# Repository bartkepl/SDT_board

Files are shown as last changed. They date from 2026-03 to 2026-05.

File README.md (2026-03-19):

# SDT (SCPI Display Thermometer)
Benchtop thermometer with SCPI and USB.

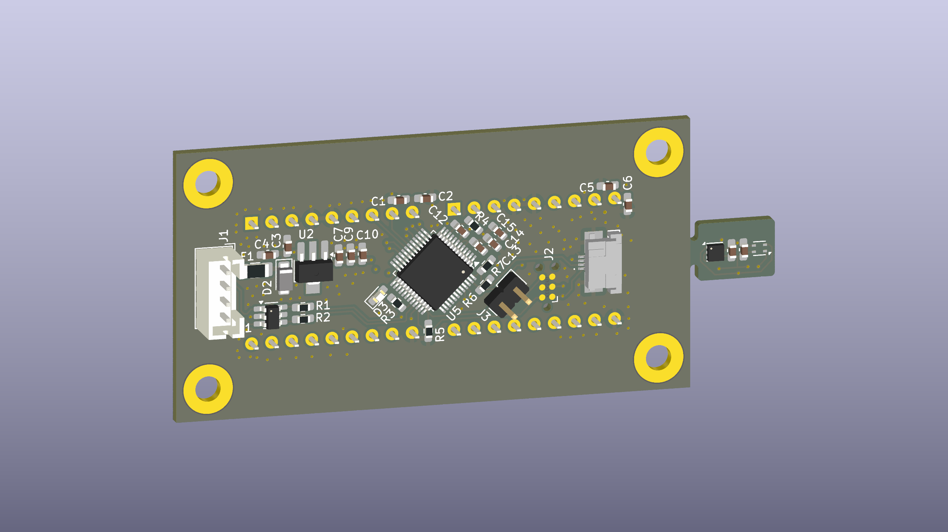
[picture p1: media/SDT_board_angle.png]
SCPI Display Thermometer


---
## Status : WIP

- [x] First revision of schematic and PCB is done.
- [x] PCB and parts ordered
- [ ] Prototypes assembled and tested
- [ ] Firmware

---
## Features:
- 4 layer board
- ARM Cortex-M0+ Processor in LQFP48 (STM32C071CBT6) 
- USB 2.0
- TMP117 or/and SHT45 for temperature measurement
----

## License and Contribution

Idea based on [SCPI Capable Thermometer](https://sebastianharnisch.de/scpi-enabled-thermometer/)

Display part & footprint from [kicad-intelligent-displays](https://github.com/74hc595/kicad-intelligent-displays) by [74hc595](https://github.com/74hc595)

USB-TMC library from TinyUSB [TinyUSB](https://github.com/hathach/tinyusb)

SCPI parser library from [scpi-parser](https://github.com/j123b567/scpi-parser) by [Jan Breuer](https://github.com/j123b567)

[MIT License](/LICENSE)

Open to contributions in both software and hardware!

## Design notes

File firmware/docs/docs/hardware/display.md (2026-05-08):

# Wyświetlacz DLR2416

SDT Board używa dwóch modułów **DLR2416** tworząc łącznie **8-znakowy wyświetlacz LED dot-matrix**.

---

## Co to jest DLR2416?

**DLR2416** to inteligentny 4-znakowy wyświetlacz LED z wbudowanym generatorem znaków. Każdy moduł zawiera:

- 4 pozycje znakowe (A–D)
- Wyświetlanie ASCII (5×7 pikseli na znak)
- Wewnętrzną pamięć RAM na 4 znaki
- Interfejs równoległy 7-bitowy (D0–D6)
- Wbudowany dekoder adresu pozycji (A0–A1 → 4 pozycje)

Dwa moduły (DISP1 i DISP2) są połączone równolegle na jednej szynie danych, wybierane oddzielnie sygnałami CE (Chip Enable).

---

## Schemat połączenia

```
STM32C071               DISP1 (pozycje 0–3)    DISP2 (pozycje 4–7)
                         ┌──────────────┐        ┌──────────────┐
PA0–PA6  ──── D0–D6  ───►│              │        │              │
PA7      ──── A0     ───►│   DLR2416    │        │   DLR2416    │
PB0      ──── A1     ───►│              │        │              │
PB1 (INV)─── WR     ───►│              │        │              │
PB2 (INV)─── CLR    ───►│              │        │              │
PB3 (INV)─── CE1    ───►│              │        │              │
PB4 (INV)─── CE2    ───►│              │        │              │
PB12(INV)─── CU     ───►│              │        │              │
PB13     ──── CUE   ───►│              │        │              │
             └──────────────┘        └──────────────┘
                                            ▲              ▲
PB5 (INV)─── CE1 ─────────────────────────┘              │
PB6 (INV)─── CE2 ──────────────────────────────────────────┘

PC14     ──── BL (PWM) ──────────── podświetlenie LED (wspólne)
```

---

## Sygnały sterujące

| Pin | Sygnał | Aktywny | Opis |
|-----|---|---|---|
| PA0–PA6 | D0–D6 | — | 7-bitowa szyna danych (kod ASCII) |
| PA7 | A0 | — | Adres pozycji bit 0 |
| PB0 | A1 | — | Adres pozycji bit 1 |
| PB1 | WR | LOW | Strob zapisu (zapis przy opadającym zboczu) |
| PB2 | CLR | LOW | Wyczyszczenie pamięci wyświetlacza |
| PB3 | CE1_1 | LOW | Chip Enable 1 — DISP1 |
| PB4 | CE2_1 | LOW | Chip Enable 2 — DISP1 |
| PB5 | CE1_2 | LOW | Chip Enable 1 — DISP2 |
| PB6 | CE2_2 | LOW | Chip Enable 2 — DISP2 |
| PB12 | CU | LOW | Chip Unit: HIGH=dane, LOW=komenda |
| PB13 | CUE | — | Chip Unit Enable — zatrzask komendy |
| PC14 | BL | PWM | Podświetlenie — TIM3 CH2, AF11 |

---

## Adresowanie pozycji

| A1 | A0 | Pozycja (4 znaki na moduł) |
|----|----|---|
| 0 | 0 | Pozycja 0 (skrajna lewa) |
| 0 | 1 | Pozycja 1 |
| 1 | 0 | Pozycja 2 |
| 1 | 1 | Pozycja 3 (skrajna prawa modułu) |

Dla 8-znakowego wyświetlacza:
- DISP1 obsługuje pozycje 0–3 (lewe 4 znaki)
- DISP2 obsługuje pozycje 4–7 (prawe 4 znaki)

---

## Protokół zapisu znaku

Procedura zapisu jednego znaku:

1. Ustaw adres: A1, A0 = numer pozycji (0–3)
2. Ustaw dane: D0–D6 = kod ASCII znaku
3. Wybierz moduł: CE1=LOW, CE2=LOW (odpowiedni moduł)
4. Strob zapisu: WR=LOW, następnie WR=HIGH

---

## Konfiguracja orientacji: SWAP i REVERSE

W `dlr2416.c` dwie stałe kompilacji wpływają na `DLR2416_WriteString8()`:

```c
#define SWAP_DISPLAYS 1   // zamień DISP1↔DISP2 (domyślnie: 1)
#define REVERSE_CHARS 1   // odwróć kolejność znaków w module pos=3-i (domyślnie: 1)
```

| Stała | Efekt |
|---|---|
| `SWAP_DISPLAYS 1` | Znaki 0–3 idą do DISP2, znaki 4–7 do DISP1 |
| `REVERSE_CHARS 1` | Pozycja i → 3-i (odwrócona kolejność wewnątrz modułu) |

Kombinacja obu pozwala dopasować wyświetlanie do fizycznej orientacji modułów na płytce bez zmiany okablowania.

---

## Sterowanie jasnością (PWM)

Jasność sterowana jest sygnałem **PWM** przez **TIM3 Channel 2** na pinie **PC14** (AF11).

| Parametr | Wartość |
|---|---|
| TIM3 ARR (Period) | **255** (8-bit, skonfigurowane w CubeMX) |
| Formuła CCR | `(1199 × percent) / 100` |
| CCR przy 1% | 11 |
| CCR przy 21% | 251 (~= ARR) |
| CCR przy ≥22% | > 255 → pin zawsze HIGH (100% brightness) |
| Domyślny CCR (init) | 600 → zawsze HIGH (pełna jasność po starcie) |
| Wyłączony | `DLR2416_PWM_Disable(GPIO_PIN_RESET)` — pin jako GPIO LOW |

```c
/* Kod w DLR2416_SetBrightness() */
uint16_t value = (1199 * percent) / 100;
__HAL_TIM_SET_COMPARE(&htim3, TIM_CHANNEL_2, value);
```

!!! warning "Efektywna regulacja tylko ≤21%"
    TIM3 ARR = 255. Dla brightness ≥ 22%, CCR przekracza ARR i pin pozostaje
    ciągle HIGH (100% jasność). Regulacja PWM działa tylko dla wartości 1–21%.
    Powyżej efekt jest identyczny — maksymalna jasność.

---

## Znak stopnia

Wyświetlacz nie obsługuje standardowego znaku stopnia (°, ASCII 0xB0). Zamiast tego DLR2416 używa własnego kodu:

```c
#define DEGREE_CHAR 0x1B   /* Specjalny znak stopnia DLR2416 */
```

Firmware używa go automatycznie podczas formatowania temperatury w trybie pomiarowym.

---

## Format wyświetlania temperatury

W trybie `SOURce 0` (pomiarowy) firmware formatuje temperaturę przez `ConvertFloatTempToChar()`.

Format: dokładnie **8 bajtów**. Ostatni bajt to `DEGREE_CHAR` = `0x1B`. **Brak litery 'C'**.

```
Mapa pozycji: [0]  [1][2][3][4][5]  [6]  [7]
               sign  cyfry/kropka    spc   °

Przykłady (hex + ASCII):
 25.47°  →  20 32 35 2E 34 37 20 1B  = " 25.47 °"
-10.11°  →  2D 31 30 2E 31 31 20 1B  = "-10.11 °"
 3.500°  →  20 33 2E 35 30 30 20 1B  = " 3.500 °"
```

Zakres:
- `|T| < 10` → format `±D.DDD` (3 miejsca po przecinku)
- `|T| ≥ 10` → format `±DD.DD` (2 miejsca po przecinku)

---

## Komunikaty błędów

Gdy wystąpi błąd czujnika, wyświetlacz pokazuje:

```
ERR:-241
ERR:-240
ERR:-230
```

- Format: `ERR:XXXX` (8 znaków)
- Czas wyświetlania: **1500 ms** na błąd
- Kolejka: max **4 błędy**
- Po wyczyszczeniu: powrót do poprzedniego widoku

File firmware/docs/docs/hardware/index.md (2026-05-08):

# Sprzęt — Przegląd

SDT Board zbudowany jest na mikrokontrolerze **STM32C071CBT6** (ARM Cortex-M0+) z trzema głównymi interfejsami sprzętowymi: I2C do czujników, USB do komunikacji z komputerem i GPIO do sterowania wyświetlaczem.

---

## Mikrokontroler

| Parametr | Wartość |
|---|---|
| Model | STM32C071CBT6 |
| Rdzeń | ARM Cortex-M0+ |
| Częstotliwość | 48 MHz (HSI48 + CRS — synchronizacja z USB) |
| Flash | 128 KB |
| RAM | 12 KB |
| Obudowa | LQFP48 |
| Narzędzie konfiguracji | STM32CubeMX (plik `SDT_board.ioc`) |

---

## Interfejsy i peryferia

| Peryferium | Zastosowanie | Uwagi |
|---|---|---|
| **I2C1** | Komunikacja z czujnikami | DMA-enabled (TX: DMA1_CH1, RX: DMA1_CH2) |
| **USB** | USB 2.0 Device (USB-TMC) | Zasilany z USB, synchronizacja zegara przez CRS |
| **TIM3 CH2** | PWM sterowanie jasnością wyświetlacza | AF11, PC14, ARR=255, formuła CCR=1199×%/100 |
| **CRC** | Walidacja danych z SHT45 | Sprzętowy kalkulator CRC |
| **DMA1_CH1/CH2** | Transmisja I2C | Odciąża CPU podczas pomiaru |

---

## Mapa pinów GPIO

### Port A — szyna danych wyświetlacza

| Pin | Sygnał | Kierunek | Opis |
|-----|---|---|---|
| PA0 | D0 | Out | Bit 0 szyny danych wyświetlacza |
| PA1 | D1 | Out | Bit 1 szyny danych wyświetlacza |
| PA2 | D2 | Out | Bit 2 szyny danych wyświetlacza |
| PA3 | D3 | Out | Bit 3 szyny danych wyświetlacza |
| PA4 | D4 | Out | Bit 4 szyny danych wyświetlacza |
| PA5 | D5 | Out | Bit 5 szyny danych wyświetlacza |
| PA6 | D6 | Out | Bit 6 szyny danych wyświetlacza |
| PA7 | A0 | Out | Linia adresowa 0 (wybór pozycji) |
| PA10 | LED | Out | Dioda LED statusu |

### Port B — sterowanie wyświetlaczem

| Pin | Sygnał | Kierunek | Logika | Opis |
|-----|---|---|---|---|
| PB0 | A1 | Out | — | Linia adresowa 1 (wybór pozycji) |
| PB1 | WR | Out | Aktywny LOW | Zapis — strob zapisu |
| PB2 | CLR | Out | Aktywny LOW | Czyszczenie pamięci wyświetlacza |
| PB3 | CE1_1 | Out | Aktywny LOW | Chip Enable 1 wyświetlacza 1 |
| PB4 | CE2_1 | Out | Aktywny LOW | Chip Enable 2 wyświetlacza 1 |
| PB5 | CE1_2 | Out | Aktywny LOW | Chip Enable 1 wyświetlacza 2 |
| PB6 | CE2_2 | Out | Aktywny LOW | Chip Enable 2 wyświetlacza 2 |
| PB12 | CU | Out | Aktywny LOW | Chip Unit — tryb DANE/KOMENDA |
| PB13 | CUE | Out | — | Chip Unit Enable — zatrzask komendy |

### Port C

| Pin | Sygnał | Kierunek | Opis |
|-----|---|---|---|
| PC14 | BL | PWM Out | Podświetlenie LED — TIM3 CH2, AF11 |

---

## Topologia I2C

```
STM32C071
    │
    ├── I2C1 (DMA) ─── SDA/SCL
    │                      │
    │              ┌────────┴────────┐
    │           TMP117            SHT45
    │          addr 0x48         addr 0x44
    │          (temp)            (T + RH)
```

Oba czujniki dzielą jeden magistralę I2C. W trybie DUAL używany jest globalny mutex (`g_i2c_active_sensor`) zapobiegający konfliktu na szynie.

---

## Schemat zasilania

| Napięcie | Źródło |
|---|---|
| VBUS 5V | USB |
| VDD 3,3V | Regulator na płytce |

---

## Linki

- [Czujniki](sensors.md) — TMP117 i SHT45 — specyfikacje i tryby pracy
- [Wyświetlacz DLR2416](display.md) — protokół i pinout

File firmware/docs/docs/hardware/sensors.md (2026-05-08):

# Czujniki

SDT Board obsługuje dwa czujniki temperatury: **TMP117** (temperatura) i **SHT45** (temperatura + wilgotność). Oba używają tego samego magistrali I2C. Wykrywane są automatycznie podczas uruchamiania — można też używać obydwu jednocześnie (tryb DUAL).

---

## TMP117 — Czujnik temperatury

### Parametry elektryczne

| Parametr | Wartość |
|---|---|
| Adres I2C | `0x48` (8-bit: `0x90`) |
| Napięcie zasilania | 1,7–5,5 V |
| Pobór prądu | 3,5 µA @ 1 pom./s |
| Zakres temperatury | -55 °C … +150 °C |
| Dokładność typowa | ±0,1 °C (0–70 °C) |
| Rozdzielczość | **7,8125 m°C/LSB** (0,0078125 °C) |
| Interfejs | I2C (standardowy / fast mode) |

### Konwersja temperatury

Temperatura przechowywana jest w rejestrze `0x00` jako 16-bitowa liczba ze znakiem (uzupełnienie do dwóch):

```
T [°C] = raw_int16 × 0.0078125
```

**Przykład:** `raw = 0x0C80` = 3200 → T = 3200 × 0.0078125 = **25,00 °C**

### Rejestry

| Adres | Nazwa | Dostęp | Opis |
|---|---|---|---|
| `0x00` | TEMP | R | Wynik pomiaru temperatury |
| `0x01` | CONFIG | R/W | Konfiguracja: tryb, CONV, AVG, alerty |
| `0x02` | THIGH | R/W | Górny próg alertu |
| `0x03` | TLOW | R/W | Dolny próg alertu |
| `0x0F` | ID | R | Identyfikator układu |

### Rejestr CONFIG (0x01) — Mapa bitów

| Bity | Nazwa | Opis |
|---|---|---|
| [15] | HIGH_ALERT | R — flaga: temperatura ≥ THIGH |
| [14] | LOW_ALERT | R — flaga: temperatura ≤ TLOW |
| [13] | DATA_READY | R — nowy pomiar gotowy |
| [12] | EEPROM_BUSY | R — EEPROM zajęty |
| [11:10] | MOD[1:0] | R/W — tryb konwersji |
| [9:7] | CONV[2:0] | R/W — cykl konwersji |
| [6:5] | AVG[1:0] | R/W — sprzętowe uśrednianie |
| [1] | SOFT_RESET | W — reset programowy (auto-zeruje się) |

**Domyślna wartość CONFIG:** `0x0220` (MOD=Continuous, CONV=1s, AVG=8x)

### Tryby konwersji (MOD)

| Wartość | SCPI | Opis |
|---|---|---|
| `0x00` | `CONTinuous` | Ciągły pomiar |
| `0x01` | `SHUTdown` | Wyłączony — minimalne zużycie energii |
| `0x03` | `ONESHot` | Jeden pomiar, potem shutdown |

### Cykl konwersji (CONV) a tryb uśredniania (AVG)

Łączny czas pomiaru = czas konwersji × liczba próbek AVG:

| CONV kod | Czas (AVG=1) | Czas (AVG=8) | Czas (AVG=32) | Czas (AVG=64) |
|---|---|---|---|---|
| 0 | 15,5 ms | 125 ms | 500 ms | 1 s |
| 1 | 125 ms | 125 ms | 500 ms | 1 s |
| 2 | 250 ms | 250 ms | 500 ms | 1 s |
| 3 | 500 ms | 500 ms | 500 ms | 1 s |
| 4 | 1 s | 1 s | 1 s | 1 s |
| 5 | 4 s | 4 s | 4 s | 4 s |
| 6 | 8 s | 8 s | 8 s | 8 s |
| 7 | 16 s | 16 s | 16 s | 16 s |

### Alerty temperatury

TMP117 posiada sprzętowe alerty temperatury — wywoływane, gdy temperatura przekroczy progi THIGH lub TLOW. Progi przechowywane są w rejestrach i używają tego samego formatu co TEMP.

```python
inst.write('SENSor:ALERt:HIGH 80.0')    # alert przy T > 80 °C
inst.write('SENSor:ALERt:LOW -10.0')    # alert przy T < -10 °C
status = inst.query('SENSor:ALERt:STATus?')
```

---

## SHT45 — Czujnik temperatury i wilgotności

### Parametry elektryczne

| Parametr | Wartość |
|---|---|
| Adres I2C | `0x44` (8-bit: `0x88`) |
| Napięcie zasilania | 1,08–3,6 V |
| Pobór prądu | ~1 µA (standby) |
| Zakres temperatury | -40 °C … +125 °C |
| Zakres wilgotności | 0 % … 100 % RH |
| Dokładność T (typowa) | ±0,1 °C |
| Dokładność RH (typowa) | ±1,0 % RH |
| Interfejs | I2C |

### Konwersja pomiarów

```
T [°C] = -45 + 175 × (raw_T / 65535)
H [%RH] = -6 + 125 × (raw_H / 65535)
```

Każdy pomiar zawiera **CRC-8** dla walidacji integralności danych (generowany i sprawdzany przez firmware).

### Komendy SHT45

| Komenda (hex) | Stała | Opis | Czas pomiaru |
|---|---|---|---|
| `0xFD` | `SHT45_PRECISION_HIGH` | Pomiar — wysoka precyzja | ~125 ms |
| `0xF6` | `SHT45_PRECISION_MEDIUM` | Pomiar — średnia precyzja | ~50 ms |
| `0xE0` | `SHT45_PRECISION_LOW` | Pomiar — niska precyzja | ~13 ms |
| `0x89` | — | Odczyt numeru seryjnego | — |
| `0x94` | — | Soft reset | — |

### Grzałka (heater)

SHT45 posiada wbudowaną grzałkę do usuwania kondensacji lub testowania odpowiedzi czujnika:

| Stała | Hex | Moc | Czas | Opis |
|---|-----|-----|---|---|
| `SHT45_HEATER_200MW_1S` | `0x39` | 200 mW | 1 s | Maksymalna moc, długi czas |
| `SHT45_HEATER_200MW_100MS` | `0x32` | 200 mW | 100 ms | Maksymalna moc, krótki czas |
| `SHT45_HEATER_110MW_1S` | `0x2F` | 110 mW | 1 s | Średnia moc, długi czas |
| `SHT45_HEATER_110MW_100MS` | `0x24` | 110 mW | 100 ms | Średnia moc, krótki czas |
| `SHT45_HEATER_20MW_1S` | `0x1E` | 20 mW | 1 s | **Domyślna** (SCPI) |
| `SHT45_HEATER_20MW_100MS` | `0x15` | 20 mW | 100 ms | Minimalna moc, krótki czas |

!!! warning "Po użyciu grzałki"
    Wyniki pomiarów po zakończeniu grzania są zawyżone. Odczekaj kilka sekund zanim użyjesz danych pomiarowych.

---

## Tryb DUAL — obydwa czujniki

Gdy oba czujniki są wykryte podczas inicjalizacji:

- **Dane temperatury** — pobierane z SHT45 (priorytet — ma też wilgotność)
- **Dane wilgotności** — pobierane z SHT45
- **TMP117** — działa równolegle (alerty, konfiguracja dostępna przez SCPI)
- **Arbitraż magistrali I2C** — globalny mutex `g_i2c_active_sensor` zapobiega konfliktom

---

## Auto-detekcja czujników

Podczas inicjalizacji firmware próbuje nawiązać komunikację z obydwoma adresami I2C:

1. Próba połączenia z TMP117 (`0x48`)
2. Próba połączenia z SHT45 (`0x44`)
3. Timeout detekcji: **5 sekund**
4. Jeśli żaden czujnik nie odpowie → SCPI błąd `-241` (Hardware missing)

```
*TST?  →  0   (czujnik wykryty i sprawny)
*TST?  →  1   (brak czujnika)
```

---

## Porównanie czujników

| Cecha | TMP117 | SHT45 |
|---|---|---|
| Temperatura | ✓ -55…+150 °C | ✓ -40…+125 °C |
| Wilgotność | ✗ | ✓ 0–100 %RH |
| Rozdzielczość T | 0,0078125 °C | zależy od precyzji |
| Sprzętowe uśrednianie | 1/8/32/64x | ✗ (softwarowe) |
| Softwarowe uśrednianie | ✗ | 1–255x |
| Alerty T | ✓ THIGH/TLOW | ✗ |
| Grzałka | ✗ | ✓ |
| Tryby konwersji | 3 tryby | precyzja LOW/MED/HIGH |
| CRC walidacja | ✗ | ✓ (CRC-8) |

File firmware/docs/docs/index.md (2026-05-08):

# SDT Board — Dokumentacja

**SDT** (SCPI Display Thermometer) to USB-termometr laboratoryjny z interfejsem SCPI, zbudowany na mikrokontrolerze STM32C071CBT6. Urządzenie mierzy temperaturę (i opcjonalnie wilgotność), wyświetla wyniki na 8-znakowym wyświetlaczu LED i udostępnia pełny interfejs sterowania przez USB.

---

## Przegląd systemu

```
┌─────────────────────────────────────────────────────────┐
│                     SDT Board                           │
│                                                         │
│  ┌──────────┐   I2C    ┌──────────┐  ┌──────────────┐  │
│  │  TMP117  │◄────────►│          │  │  DLR2416     │  │
│  │  (temp)  │          │STM32C071 │  │  8-znak LED  │  │
│  └──────────┘   I2C    │  CBT6    │─►│  wyświetlacz │  │
│  ┌──────────┐◄────────►│          │  └──────────────┘  │
│  │  SHT45   │          │          │                     │
│  │ (T + RH) │          │  USB-TMC │                     │
│  └──────────┘          └────┬─────┘                     │
│                             │                           │
└─────────────────────────────┼───────────────────────────┘
                              │ USB 2.0
                       ┌──────▼──────┐
                       │     PC      │
                       │  PyVISA /   │
                       │  LabVIEW /  │
                       │  Terminal   │
                       └─────────────┘
```

---

## Parametry urządzenia

| Cecha | Wartość |
|---|---|
| MCU | STM32C071CBT6 (ARM Cortex-M0+, 48 MHz) |
| Flash | 128 KB |
| RAM | 12 KB |
| Komunikacja | USB 2.0 Device — klasa USB-TMC |
| Protokół | SCPI (IEEE 488.2) |
| Identyfikacja | `bartkepl,SDT,<serial>,1.0` |
| Czujniki | TMP117 i/lub SHT45 (auto-detekcja) |
| Wyświetlacz | 8-znakowy LED dot-matrix (DLR2416 × 2) |
| Jasność | Regulowana PWM 1–100% |

---

## Obsługiwane czujniki

| Czujnik | Temperatura | Wilgotność | Adres I2C | Uwagi |
|---|---|---|---|---|
| TMP117 | -55 °C … +150 °C, ±0,1 °C | — | 0x48 | Wysokoprecyzyjny, alerty T |
| SHT45 | -40 °C … +125 °C | 0–100 % RH | 0x44 | Temp + wilgotność, grzałka |

Urządzenie wykrywa czujniki automatycznie podczas uruchamiania. Gdy oba są podłączone, działa w trybie **DUAL** — dane temperatury i wilgotności są zbierane z SHT45, a TMP117 może być używany równolegle.

---

## Szybki start

```bash
pip install pyvisa pyvisa-py
```

```python
import pyvisa
rm = pyvisa.ResourceManager('@py')
# VID=0xCAFE, PID=0x4000, numer seryjny USB: "SDT_<8charHash>"
inst = rm.open_resource('USB0::0xCAFE::0x4000::SDT_YOURHASH::INSTR')
print(inst.query('*IDN?'))
print(inst.query('SENSor:TEMPerature?'))
```

Więcej przykładów: [Pierwsze kroki](getting-started.md)

---

## Komendy SCPI

Urządzenie obsługuje ponad 30 komend SCPI:

- **[IEEE 488.2](scpi/ieee488.md)** — `*IDN?`, `*RST`, `*TST?` i inne standardowe
- **[SYSTem](scpi/system.md)** — błędy, wersja, ID MCU, reset, bootloader DFU
- **[SENSor](scpi/sensor.md)** — temperatura, wilgotność, tryby pracy, alerty
- **[DISPlay](scpi/display.md)** — jasność, stan, tekst, źródło danych

---

## Zasoby zewnętrzne

- Biblioteka SCPI: [scpi-parser (j123b567)](https://github.com/j123b567/scpi-parser)
- Stos USB: [TinyUSB](https://github.com/hathach/tinyusb)
- Inspiracja projektem: [Sebastian Harnisch — SCPI Thermometer](https://sebastianharnisch.de/scpi-enabled-thermometer/)

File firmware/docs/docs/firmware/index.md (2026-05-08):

# Architektura Firmware

Firmware SDT Board napisany jest w języku C (STM32 HAL + bare-metal) i oparty na współbieżnym modelu zadań (cooperative multitasking) — bez RTOS-a.

---

## Diagram przepływu danych

```
USB Host (PC)
      │
      │  USB 2.0 / USB-TMC
      ▼
┌─────────────────┐
│   TinyUSB       │  usbtmc_app.c
│   (USB stack)   │  — odbiera bajty USB
└────────┬────────┘  — buforuje komendy SCPI
         │ dane tekstowe (SCPI)
         ▼
┌─────────────────┐
│  SCPI Parser    │  libscpi / scpi-def.c
│  (libscpi)      │  — parsuje komendy
└───┬─────────────┘  — wywołuje handlery
    │           │
    ▼           ▼
┌───────┐  ┌───────────┐
│Sensor │  │  Display  │  — ustaw jasność
│ API   │  │  API      │  — ustaw tekst
│       │  │           │  — zmień źródło
└───┬───┘  └─────┬─────┘
    │             │
    ▼             ▼
┌─────────────────────────────────┐
│         I2C + GPIO              │
│  TMP117  │  SHT45  │  DLR2416  │
└─────────────────────────────────┘
```

---

## Pętla główna (main loop)

`Core/Src/main.c` — uruchamia po inicjalizacji peryferiów nieskończoną pętlę zadań:

```c
while (1) {
    tud_task();                /* TinyUSB — obsługa USB */
    usbtmc_app_task_iter();    /* USB-TMC — SCPI request/response */
    Sensor_Task();             /* Czujnik — maszyna stanów I2C */
    SCPI_Main_Poll();          /* SCPI — propagacja błędów czujnika */
    Display_task();            /* Wyświetlacz — odświeżanie LED */
}
```

Wszystkie zadania są **nieblokujące** (non-blocking) — każde sprawdza swój stan, wykonuje krok i oddaje sterowanie. Synchronizacja oparta na 1 ms timerze systemowym (`SysTick`).

---

## Inicjalizacja

Kolejność inicjalizacji przy starcie (`main.c`):

```
── HAL (generowane przez CubeMX) ──────────────────────────────────
 1. HAL_Init()            — inicjalizacja HAL STM32
 2. SystemClock_Config()  — HSI48 48 MHz + CRS synchronizacja z USB
 3. MX_GPIO_Init()        — GPIO (D0-D6, A0-A1, CE, WR, CLR, LED)
 4. MX_DMA_Init()         — DMA1 CH1/CH2 (I2C TX/RX)
 5. MX_I2C1_Init()        — I2C1 (timing 0x00402D41)
 6. MX_TIM3_Init()        — TIM3 PWM CH2 (podświetlenie, ARR=255)
 7. MX_USB_PCD_Init()     — USB DRD FS
 8. MX_CRC_Init()         — sprzętowy CRC

── Kod użytkownika ─────────────────────────────────────────────────
 9. Sensor_Init(&hi2c1)   — detekcja TMP117/SHT45, konfiguracja I2C
10. tud_init()            — TinyUSB stack
11. SCPI_Main_Init()      — parser SCPI + rejestracja komend + IDN
12. Display_Init()        — DLR2416_Init() + domyślna jasność 4%
```

---

## Moduły firmware

### `Core/Src/main.c`
Punkt wejścia. Inicjalizacja peryferiów i pętla główna.

### `Core/Src/usbtmc_app.c`
Obsługa protokołu USB-TMC:
- Odbieranie pakietów BULK OUT (komendy SCPI)
- Wysyłanie pakietów BULK IN (odpowiedzi SCPI)
- Zarządzanie stanem request/response (maszyna stanów)
- Wywołanie `SCPI_Main_Input()` gdy komenda jest kompletna

### `App/libscpi/src/scpi-def.c`
Rejestracja i implementacja wszystkich komend SCPI:
- Lista komend (`scpi_commands[]`) — mapowanie wzorców na handlery
- Implementacja 30+ handlerów C
- Propagacja błędów do kolejki SCPI
- Integracja z modułami sensor i display

### `App/sensor/sensor.c`
Zunifikowany interfejs czujnika:
- Auto-detekcja TMP117 i SHT45 na I2C podczas `Sensor_Init()`
- `Sensor_Task()` — wywołuje `TMP117_Task()` lub `SHT45_Task()` w zależności od wykrytego czujnika
- `g_sensor` — globalny obiekt z danymi (typ, temperatura, wilgotność, flagi)
- Propagacja błędów przez `Sensor_GetAndClearError()`
- Arbitraż magistrali I2C przez `g_i2c_active_sensor`

### `App/sensor/tmp117.c`
Sterownik TMP117:
- Maszyna stanów (26 stanów) obsługująca wszystkie transakcje I2C
- Asynchroniczny odczyt przez DMA — `TMP117_I2C_TxComplete_Callback()` / `TMP117_I2C_RxComplete_Callback()`
- Odczyt: temperatura, ID, CONFIG, THIGH, TLOW
- Zapis: CONFIG (tryb/AVG/CONV), THIGH, TLOW
- Obsługa timeout DMA (100 ms)

### `App/sensor/sht45.c`
Sterownik SHT45:
- Maszyna stanów (22 stany) obsługująca pomiar, serial, reset i grzałkę
- Asynchroniczny odczyt przez DMA
- Walidacja CRC-8 dla każdego pomiaru
- Softwarowe uśrednianie (akumulator próbek)
- Timeout DMA (100 ms)

### `App/D2416/display.c`
Zarządzanie wyświetlaczem:
- `Display_task()` — wywoływany co 100 ms, odświeża wyświetlacz
- Wybór źródła: pomiar (auto-format) lub tekst użytkownika
- Kolejka błędów (4 wpisy FIFO), każdy wyświetlany 1500 ms
- Sterowanie jasnością przez `DLR2416_SetBrightness()`

### `App/D2416/dlr2416.c`
Niskopoziomowy sterownik DLR2416:
- Bit-banged GPIO dla szyny danych i sygnałów sterujących
- `DLR2416_WriteChar()` — zapis jednego znaku na pozycję
- `DLR2416_WriteString8()` — zapis 8 znaków na cały wyświetlacz
- `DLR2416_SetBrightness()` — sterowanie PWM TIM3
- `DLR2416_PWM_Enable()` / `DLR2416_PWM_Disable()` — włącz/wyłącz

### `App/Utils/Utils.c`
Funkcje pomocnicze:
- `SysTimZeroTimer1ms_u16()` — start timera 1 ms
- `SysTimTestTimer1ms_u16()` — sprawdzenie czy minął czas (wrap-safe, 16-bit)
- `serial_get()` — **8-znakowy** FNV-1a hash z 20 B danych MCU (DEVID+REVID+UID)
- `serial_get_full()` — **40-znakowy** hex dump tych 20 bajtów

---

## Obsługa błędów

```
Sensor_Task()
    │
    ├── Błąd I2C → ustaw SENSOR_ERR_COMM
    ├── Timeout DMA → ustaw SENSOR_ERR_TIMEOUT
    └── Błąd CRC → ustaw SENSOR_ERR_DATA

SCPI_Main_Poll()  (wywoływany co iterację)
    │
    └── Sensor_GetAndClearError()
           │
           ├── SENSOR_ERR_NOT_FOUND → SCPI_ErrorPush(-241)
           ├── SENSOR_ERR_COMM → SCPI_ErrorPush(-240)
           ├── SENSOR_ERR_TIMEOUT → SCPI_ErrorPush(-365)
           └── SENSOR_ERR_DATA → SCPI_ErrorPush(-230)

SCPI_Error callback
    │
    └── Display_ShowError(code)  → wyświetl "ERR:XXXX" przez 1.5s
```

---

## Okresy zadań

| Zadanie | Okres wywołania | Uwagi |
|---|---|---|
| `tud_task()` | Co iterację pętli | USB — as fast as possible |
| `usbtmc_app_task_iter()` | Co iterację pętli | USB-TMC state machine |
| `Sensor_Task()` | Co iterację pętli | Wewnętrzny timer 10 ms |
| `SCPI_Main_Poll()` | Co iterację pętli | Sprawdza błędy czujnika |
| `Display_task()` | Co iterację pętli | Wewnętrzny timer 100 ms |
| Odczyt czujnika | 1000 ms domyślnie | Konfigurowalny przez SCPI |

---

## Linki do API

- [API czujników](sensor-api.md) — funkcje C dla TMP117, SHT45 i warstwy sensor
- [API wyświetlacza](display-api.md) — funkcje C dla display i DLR2416

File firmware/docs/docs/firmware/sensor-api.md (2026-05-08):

# API czujników (C)

Dokumentacja publicznych funkcji i typów danych modułów sensor, tmp117 i sht45.

---

## Typy danych

### `SensorType_t` (`sensor.h`)

Enum identyfikujący aktywny czujnik.

```c
typedef enum {
    SENSOR_NONE  = 0,   // Żaden czujnik nie wykryty
    SENSOR_TMP117,      // Tylko TMP117
    SENSOR_SHT45,       // Tylko SHT45
    SENSOR_DUAL,        // Oba czujniki
    SENSOR_ERROR,       // Błąd komunikacji z czujnikiem
} SensorType_t;
```

### `SensorError_t` (`sensor.h`)

Enum błędów generowanych przez moduł sensor. Propagowane przez `SCPI_Main_Poll()` do kolejki błędów SCPI.

```c
typedef enum {
    SENSOR_ERR_NONE      = 0,  // Brak błędu
    SENSOR_ERR_NOT_FOUND,      // Czujnik nie wykryty → SCPI -241
    SENSOR_ERR_COMM,           // Błąd I2C           → SCPI -240
    SENSOR_ERR_TIMEOUT,        // Timeout DMA        → SCPI -365
    SENSOR_ERR_DATA,           // Błąd CRC / dane    → SCPI -230
} SensorError_t;
```

### `SensorData_t` (`sensor.h`)

Globalna struktura z danymi pomiarowymi. Dostępna jako `g_sensor`.

```c
typedef struct {
    SensorType_t type;          // Aktualny typ czujnika
    float        fTemp;         // Temperatura [°C]
    float        fHum;          // Wilgotność [%RH] (NaN dla TMP117)
    uint32_t     usSensorId;    // ID czujnika (serial number)
    uint8_t      ucValidFlag;   // 1 = dane ważne i aktualne
    uint8_t      ucNewDataFlag; // 1 = nowe dane dostępne
    uint8_t      ucInitializedFlag; // 1 = czujnik zainicjowany
    uint16_t     sMeasTaskTimer;    // Timer zadań pomiarowych
} SensorData_t;

extern SensorData_t g_sensor;
```

### `TMP117_Mode_t` (`tmp117.h`)

```c
typedef enum {
    TMP117_MODE_CONTINUOUS = 0x00,  // Ciągły pomiar
    TMP117_MODE_SHUTDOWN   = 0x01,  // Wyłączony
    TMP117_MODE_ONESHOT    = 0x03,  // Jeden pomiar
} TMP117_Mode_t;
```

### `TMP117_Averaging_t` (`tmp117.h`)

```c
typedef enum {
    TMP117_AVG_1  = 0x00,   // Brak uśredniania
    TMP117_AVG_8  = 0x01,   // 8x (domyślny)
    TMP117_AVG_32 = 0x02,   // 32x
    TMP117_AVG_64 = 0x03,   // 64x
} TMP117_Averaging_t;
```

### `SHT45_Precision_t` (`sht45.h`)

```c
typedef enum {
    SHT45_PRECISION_HIGH   = 0xFD,  // ~125 ms (domyślna)
    SHT45_PRECISION_MEDIUM = 0xF6,  // ~50 ms
    SHT45_PRECISION_LOW    = 0xE0,  // ~13 ms
} SHT45_Precision_t;
```

### `SHT45_HeaterMode_t` (`sht45.h`)

```c
typedef enum {
    SHT45_HEATER_200MW_1S    = 0x39,
    SHT45_HEATER_200MW_100MS = 0x32,
    SHT45_HEATER_110MW_1S    = 0x2F,
    SHT45_HEATER_110MW_100MS = 0x24,
    SHT45_HEATER_20MW_1S     = 0x1E,  // używana przez SCPI
    SHT45_HEATER_20MW_100MS  = 0x15,
} SHT45_HeaterMode_t;
```

---

## Funkcje warstwy `sensor.h`

### Inicjalizacja i zadania

```c
void Sensor_Init(I2C_HandleTypeDef *hi2c);
```
Inicjalizuje moduł sensor. Próbuje wykryć TMP117 i/lub SHT45 na magistrali I2C. Ustawia `g_sensor.type`.

```c
void Sensor_Task(void);
```
Główne zadanie czujnika — wywołuj co 1–10 ms w pętli głównej. Obsługuje maszyny stanów TMP117 i SHT45.

```c
SensorError_t Sensor_GetAndClearError(void);
```
Zwraca ostatni błąd i zeruje go. Wywoływana przez `SCPI_Main_Poll()` do propagacji błędów do SCPI.

### Callbacki I2C (wywoływane z przerwań HAL)

```c
void Sensor_I2C_TxComplete_Callback(void);
void Sensor_I2C_RxComplete_Callback(void);
void Sensor_I2C_Error_Callback(void);
```

---

## Funkcje SHT45 — `sensor.h`

### Konfiguracja

```c
void     Sensor_SHT45_SetReadPeriod(uint16_t periodMs);
uint16_t Sensor_SHT45_GetReadPeriod(void);
```
Ustawia/pobiera okres pomiarów SHT45 w milisekundach (zakres: 50–60000 ms).

```c
void    Sensor_SHT45_SetAverageCount(uint8_t count);
uint8_t Sensor_SHT45_GetAverageCount(void);
```
Ustawia/pobiera liczbę próbek do softwarowego uśredniania (zakres: 1–255).

```c
void    Sensor_SHT45_SetMeasurementPrecision(uint8_t precision);
uint8_t Sensor_SHT45_GetMeasurementPrecision(void);
```
Ustawia/pobiera precyzję pomiaru — wartości z `SHT45_Precision_t`.

### Komendy

```c
void Sensor_SHT45_RequestHeater(uint8_t ucHeaterMode);
```
Zleca aktywację grzałki. `ucHeaterMode` to wartość z `SHT45_HeaterMode_t`.

```c
void Sensor_SHT45_RequestSoftReset(void);
```
Zleca programowy reset SHT45.

---

## Funkcje TMP117 — `sensor.h`

### Tryb i konfiguracja konwersji

```c
void    Sensor_TMP117_SetMode(uint8_t mode);
uint8_t Sensor_TMP117_GetMode(void);
```
Tryb konwersji — wartości z `TMP117_Mode_t`.

```c
void    Sensor_TMP117_SetConvRate(uint8_t rate);
uint8_t Sensor_TMP117_GetConvRate(void);
```
Cykl konwersji CONV[2:0] — zakres 0–7.

```c
void    Sensor_TMP117_SetAvgHW(uint8_t avg);
uint8_t Sensor_TMP117_GetAvgHW(void);
```
Sprzętowe uśrednianie — wartości z `TMP117_Averaging_t` (0=1x, 1=8x, 2=32x, 3=64x).

```c
void     Sensor_TMP117_SetReadPeriod(uint16_t periodMs);
uint16_t Sensor_TMP117_GetReadPeriod(void);
```
Okres pomiarów w ms (zakres: 50–60000 ms).

### Alerty temperatury

```c
void  Sensor_TMP117_SetAlertHigh(float fTemp);
float Sensor_TMP117_GetAlertHigh(void);

void  Sensor_TMP117_SetAlertLow(float fTemp);
float Sensor_TMP117_GetAlertLow(void);
```
Progi alertu w °C. Zakres: -55,0 do +150,0 °C.

```c
uint8_t Sensor_TMP117_GetAlertStatus(void);
```
Odczyt statusu alertu. Zwraca bitfield:

| Bit | Znaczenie |
|-----|---|
| bit 1 (`0x02`) | HIGH alert aktywny (T ≥ THIGH) |
| bit 0 (`0x01`) | LOW alert aktywny (T ≤ TLOW) |
| bit 2 (`0x04`) | DATA_READY (nowy pomiar gotowy) |

### Soft reset

```c
void Sensor_TMP117_RequestSoftReset(void);
```

---

## Funkcje pomocnicze — `Utils.h`

```c
const char *serial_get(void);
```
Zwraca **8-znakowy** ciąg hex. Obliczony jako FNV-1a hash 20 bajtów:
`HAL_GetDEVID()` (4B) + `HAL_GetREVID()` (4B) + `UID_Word0/1/2` (12B).  
Używany przez `*IDN?` i `SYSTem:ID? SHORT`.

```c
const char *serial_get_full(void);
```
Zwraca **40-znakowy** ciąg hex — bezpośredni dump tych samych 20 bajtów.  
Używany przez `SYSTem:ID? LONG`.

---

## Przykłady użycia

### Odczyt temperatury

```c
if (g_sensor.ucValidFlag && g_sensor.type != SENSOR_NONE) {
    float temp = g_sensor.fTemp;
    // użyj temperatury
}
```

### Konfiguracja TMP117 przez API

```c
// Tryb najszybszy: 15.5 ms konwersja, bez uśredniania
Sensor_TMP117_SetConvRate(0);
Sensor_TMP117_SetAvgHW((uint8_t)TMP117_AVG_1);
Sensor_TMP117_SetReadPeriod(50);

// Alert przy 80 °C
Sensor_TMP117_SetAlertHigh(80.0f);
Sensor_TMP117_SetAlertLow(-10.0f);
```

### Konfiguracja SHT45

```c
// Niska precyzja, szybki pomiar, bez uśredniania
Sensor_SHT45_SetMeasurementPrecision((uint8_t)SHT45_PRECISION_LOW);
Sensor_SHT45_SetAverageCount(1);
Sensor_SHT45_SetReadPeriod(100);

// Aktywuj grzałkę 20 mW na 1 s
Sensor_SHT45_RequestHeater((uint8_t)SHT45_HEATER_20MW_1S);
```

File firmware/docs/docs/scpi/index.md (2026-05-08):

# Komendy SCPI — Przegląd

SDT Board implementuje protokół **SCPI** (Standard Commands for Programmable Instruments) w wersji 1999.0, zgodny z IEEE 488.2, przesyłany przez interfejs **USB-TMC** (USB Test and Measurement Class).

---

## Grupy komend

| Grupa | Prefiks | Opis |
|---|---|---|
| [IEEE 488.2](ieee488.md) | `*` | Standardowe komendy mandatoryjne |
| [SYSTem](system.md) | `SYST:` | Zarządzanie systemem, błędy, reset, bootloader |
| [SENSor](sensor.md) | `SENS:` | Czujniki — temperatura, wilgotność, konfiguracja |
| [DISPlay](display.md) | `DISP:` | Sterowanie wyświetlaczem LED |

---

## Konwencje składni SCPI

### Skróty komend

SCPI pozwala używać skróconych form komend — litery pisane wielkimi literami tworzą obowiązkowe minimum:

| Pełna forma | Skrót | Opis |
|---|---|---|
| `SENSor:TEMPerature?` | `SENS:TEMP?` | Odczyt temperatury |
| `DISPlay:BRIGhtness` | `DISP:BRIG` | Jasność wyświetlacza |
| `SYSTem:ERRor:NEXT?` | `SYST:ERR:NEXT?` | Następny błąd |

### Parametry opcjonalne

Parametry w nawiasach kwadratowych `[...]` są opcjonalne:

```
SYSTem:ERRor[:NEXT]?   →  SYSTem:ERRor?  lub  SYSTem:ERRor:NEXT?
SYSTem:ID? [SHORT|LONG]  →  SYSTem:ID?  lub  SYSTem:ID? LONG
```

### Typy wartości

| Typ | Przykład | Opis |
|-----|---|---|
| `<bool>` | `0`, `1`, `ON`, `OFF` | Wartość logiczna |
| `<uint>` | `50`, `100` | Liczba całkowita nieujemna |
| `<float>` | `23.5`, `-10.0` | Liczba zmiennoprzecinkowa |
| `<string>` | `"HELLO "` | Ciąg znaków w cudzysłowie |
| `<choice>` | `HIGH`, `LOW` | Wybór ze zdefiniowanej listy |

---

## Kolejka błędów SCPI

Urządzenie posiada kolejkę błędów (rozmiar: 16) zgodną ze standardem SCPI. Każda nieprawidłowa operacja dodaje do niej wpis.

```python
# Odczyt liczby błędów
count = inst.query('SYSTem:ERRor:COUNt?')

# Odczyt kolejnych błędów
err = inst.query('SYSTem:ERRor:NEXT?')
# Format: <kod>,"<opis>"
# Przykład: -222,"Data out of range"

# Wyczyszczenie rejestru statusu (nie kolejki!)
inst.write('*CLS')
```

Szczegółowa lista kodów błędów: [SYSTem — Kody błędów](system.md#kody-bledow-scpi).

---

## Wymagania sprzętowe a dostępność komend

Niektóre komendy są dostępne tylko dla konkretnych czujników:

| Komenda | TMP117 | SHT45 | DUAL |
|---|---|---|---|
| `SENSor:TEMPerature?` | ✓ | ✓ | ✓ |
| `SENSor:HUMidity?` | NaN | ✓ | ✓ |
| `SENSor:ALERt:*` | ✓ | ✗ | ✓ |
| `SENSor:MODe` | ✓ | ✗ | ✓ |
| `SENSor:CONVrate` | ✓ | ✗ | ✓ |
| `SENSor:PRECision` | ✗ | ✓ | ✓ |
| `SENSor:HEATer` | ✗ | ✓ | ✓ |
| `SENSor:AVErage` | 1/8/32/64 | 1–255 | ✓ |

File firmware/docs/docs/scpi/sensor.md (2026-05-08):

# SENSor — Komendy czujnika

Komendy `SENSor:` służą do odczytu pomiarów i konfiguracji czujników temperatury i wilgotności. Część komend dostępna jest tylko dla określonego czujnika.

!!! info "Dostępność"
    Komenda może zwrócić błąd `-221` (`Settings conflict`), jeśli jest skierowana do czujnika, który jej nie obsługuje — np. `SENSor:HEATer` dla TMP117.

---

## Komendy ogólne

### `SENSor:TYPE?`

Zwraca typ aktualnie wykrytego czujnika.

**Składnia:** `SENSor:TYPE?`  
**Odpowiedź:** string

| Odpowiedź | Znaczenie |
|---|---|
| `"SHT45"` | Podłączony czujnik SHT45 (T + RH) |
| `"TMP117"` | Podłączony czujnik TMP117 (tylko T) |
| `"DUAL"` | Oba czujniki — TMP117 i SHT45 |
| `"UNKNWN"` | Brak czujnika lub błąd |

```python
sensor_type = inst.query('SENSor:TYPE?')
```

---

### `SENSor:TEMPerature?`

Odczytuje ostatnio zmierzoną temperaturę.

**Składnia:** `SENSor:TEMPerature?`  
**Odpowiedź:** float w stopniach Celsjusza

| Czujnik | Zakres | Rozdzielczość |
|---|---|---|
| TMP117 | -55 … +150 °C | 0,0078125 °C/LSB |
| SHT45 | -40 … +125 °C | zależy od trybu precyzji |

```python
temp = float(inst.query('SENSor:TEMPerature?'))
print(f'{temp:.4f} °C')
```

!!! warning "Błędy"
    - `-240` — błąd sprzętowy (I2C)
    - `-241` — czujnik nie wykryty
    - `-230` — dane nieważne (np. brak pierwszego pomiaru)

---

### `SENSor:HUMidity?`

Odczytuje ostatnio zmierzoną wilgotność względną.

**Składnia:** `SENSor:HUMidity?`  
**Odpowiedź:** float w procentach `%RH`, lub `NaN` dla TMP117

| Czujnik | Odpowiedź |
|---|---|
| SHT45 | 0,0 … 100,0 %RH |
| TMP117 | `NaN` (czujnik nie mierzy wilgotności) |
| DUAL | jak SHT45 |

```python
hum = float(inst.query('SENSor:HUMidity?'))
if not math.isnan(hum):
    print(f'{hum:.2f} %RH')
```

---

### `SENSor:ID?`

Odczytuje numer seryjny czujnika.

**Składnia:** `SENSor:ID?`  
**Odpowiedź:** uint32 — numer seryjny (uint32)

| Czujnik | Źródło |
|---|---|
| TMP117 | Rejestr ID (adres 0x0F) |
| SHT45 | Numer seryjny 32-bit (komenda 0x89) |

```python
sensor_id = inst.query('SENSor:ID?')
```

---

### `SENSor:READperiod?` / `SENSor:READperiod`

Odczytuje lub ustawia okres między pomiarami czujnika.

**Składnia odczytu:** `SENSor:READperiod?`  
**Składnia zapisu:** `SENSor:READperiod <ms>`  
**Parametr:** uint — okres w milisekundach  
**Zakres:** 50 … 60000 ms  
**Wartość domyślna:** 1000 ms  
**Odpowiedź (odczyt):** uint (ms)

```python
print(inst.query('SENSor:READperiod?'))   # 1000
inst.write('SENSor:READperiod 500')        # ustaw 500 ms
```

!!! note
    Dotyczy okresu odświeżania firmware (jak często MCU odpytuje czujnik), a nie bezpośrednio prędkości konwersji sprzętowej.

---

### `SENSor:AVErage?` / `SENSor:AVErage`

Odczytuje lub ustawia liczbę próbek do uśredniania.

**Składnia odczytu:** `SENSor:AVErage?`  
**Składnia zapisu:** `SENSor:AVErage <count>`  
**Odpowiedź (odczyt):** uint

| Czujnik | Dopuszczalne wartości | Opis |
|---|---|---|
| SHT45 | 1–255 | Softwarowe uśrednianie N próbek |
| TMP117 | **tylko:** 1, 8, 32, 64 | Sprzętowe uśrednianie w konfiguracji układu |

```python
# SHT45: ustaw 10-krotne uśrednianie
inst.write('SENSor:AVErage 10')

# TMP117: ustaw 8-krotne (sprzętowe)
inst.write('SENSor:AVErage 8')
print(inst.query('SENSor:AVErage?'))   # 8
```

!!! warning "TMP117"
    Dla TMP117 dopuszczalne są **wyłącznie** wartości `1`, `8`, `32`, `64`. Inna wartość zwróci błąd `-222` (Data out of range).

---

### `SENSor:PRECision?` / `SENSor:PRECision`

Odczytuje lub ustawia precyzję pomiaru SHT45. Dla TMP117 odczyt zwraca `NaN`.

**Składnia odczytu:** `SENSor:PRECision?`  
**Składnia zapisu:** `SENSor:PRECision <mode>`  
**Czujnik:** SHT45 (dla TMP117: błąd `-221`)  
**Odpowiedź (odczyt):** string

| Wartość | Czas pomiaru | Komenda SHT45 |
|---|---|---|
| `HIGH` | ~125 ms | `0xFD` |
| `MEDIUM` | ~50 ms | `0xF6` |
| `LOW` | ~13 ms | `0xE0` |

```python
print(inst.query('SENSor:PRECision?'))    # "HIGH"
inst.write('SENSor:PRECision MEDIUM')
```

---

### `SENSor:SOFTReset`

Wykonuje programowy reset czujnika.

**Składnia:** `SENSor:SOFTReset`  
**Parametry:** brak  
**Czujniki:** TMP117 i SHT45 (obydwa jeśli DUAL)

```python
inst.write('SENSor:SOFTReset')
```

---

### `SENSor:HEATer`

Aktywuje wbudowaną grzałkę SHT45 (np. do usunięcia kondensacji).

**Składnia:** `SENSor:HEATer`  
**Parametry:** brak  
**Czujnik:** SHT45 tylko (dla TMP117: błąd `-221`)  
**Domyślny tryb:** 20 mW przez 1 sekundę

```python
inst.write('SENSor:HEATer')
```

!!! info
    Grzałka uruchamia się na 1 sekundę z mocą 20 mW (tryb `SHT45_HEATER_20MW_1S`, kod `0x1E`). Po jej zakończeniu automatycznie wyłącza się. Wyniki pomiarów podczas działania grzałki mogą być zawyżone — należy odczekać kilka sekund.

---

## Komendy specyficzne dla TMP117

### `SENSor:ALERt:HIGH?` / `SENSor:ALERt:HIGH`

Odczytuje lub ustawia górny próg alertu temperatury TMP117.

**Składnia odczytu:** `SENSor:ALERt:HIGH?`  
**Składnia zapisu:** `SENSor:ALERt:HIGH <temp>`  
**Parametr:** float — temperatura w °C  
**Zakres:** -55,0 … +150,0 °C  
**Odpowiedź (odczyt):** float (°C)  
**Czujnik:** TMP117 lub DUAL

```python
print(inst.query('SENSor:ALERt:HIGH?'))   # 80.0
inst.write('SENSor:ALERt:HIGH 80.0')
```

---

### `SENSor:ALERt:LOW?` / `SENSor:ALERt:LOW`

Odczytuje lub ustawia dolny próg alertu temperatury TMP117.

**Składnia odczytu:** `SENSor:ALERt:LOW?`  
**Składnia zapisu:** `SENSor:ALERt:LOW <temp>`  
**Parametr:** float — temperatura w °C  
**Zakres:** -55,0 … +150,0 °C  
**Odpowiedź (odczyt):** float (°C)  
**Czujnik:** TMP117 lub DUAL

```python
inst.write('SENSor:ALERt:LOW -10.0')
print(inst.query('SENSor:ALERt:LOW?'))   # -10.0
```

---

### `SENSor:ALERt:STATus?`

Odczytuje stan alertu temperatury TMP117 na podstawie bitów w rejestrze CONFIG.

**Składnia:** `SENSor:ALERt:STATus?`  
**Parametry:** brak  
**Odpowiedź:** string  
**Czujnik:** TMP117 lub DUAL

| Odpowiedź | Opis | Bit w CONFIG |
|---|---|---|
| `"HIGH"` | Temperatura ≥ THIGH | bit 15 |
| `"LOW"` | Temperatura ≤ TLOW | bit 14 |
| `"READY"` | Nowy pomiar gotowy (Data Ready) | bit 13 |
| `"NONE"` | Brak aktywnych alertów | — |

```python
status = inst.query('SENSor:ALERt:STATus?')
if status.strip() == '"HIGH"':
    print('ALERT: temperatura powyżej progu!')
```

---

### `SENSor:MODe?` / `SENSor:MODe`

Odczytuje lub ustawia tryb konwersji TMP117.

**Składnia odczytu:** `SENSor:MODe?`  
**Składnia zapisu:** `SENSor:MODe <mode>`  
**Czujnik:** TMP117 lub DUAL

| Parametr | Wartość CONFIG | Opis |
|---|---|---|
| `CONTinuous` | `0x00` | Ciągły pomiar (domyślny) |
| `SHUTdown` | `0x01` | Wyłączony — oszczędzanie energii |
| `ONESHot` | `0x03` | Jeden pomiar, potem shutdown |

```python
print(inst.query('SENSor:MODe?'))       # "CONTINUOUS"
inst.write('SENSor:MODe SHUTdown')
inst.write('SENSor:MODe CONTinuous')
```

---

### `SENSor:CONVrate?` / `SENSor:CONVrate`

Odczytuje lub ustawia czas cyklu konwersji TMP117 (CONV[2:0]).

**Składnia odczytu:** `SENSor:CONVrate?`  
**Składnia zapisu:** `SENSor:CONVrate <rate>`  
**Parametr:** uint 0–7  
**Czujnik:** TMP117 lub DUAL

| Kod (rate) | Czas konwersji | Uwagi |
|---|---|---|
| `0` | 15,5 ms | Najkrótszy |
| `1` | 125 ms | |
| `2` | 250 ms | |
| `3` | 500 ms | |
| `4` | 1 s | **Domyślny** |
| `5` | 4 s | |
| `6` | 8 s | |
| `7` | 16 s | Najdłuższy |

```python
print(inst.query('SENSor:CONVrate?'))   # 4  (= 1s)
inst.write('SENSor:CONVrate 0')          # najszybszy tryb
```

---

## Podsumowanie

| Komenda | Parametr | Odpowiedź | TMP117 | SHT45 |
|---|---|---|---|---|
| `SENSor:TYPE?` | — | string | ✓ | ✓ |
| `SENSor:TEMPerature?` | — | float °C | ✓ | ✓ |
| `SENSor:HUMidity?` | — | float %RH / NaN | NaN | ✓ |
| `SENSor:ID?` | — | uint32 | ✓ | ✓ |
| `SENSor:READperiod?` | — | uint ms | ✓ | ✓ |
| `SENSor:READperiod <ms>` | 50–60000 | — | ✓ | ✓ |
| `SENSor:AVErage?` | — | uint | 1/8/32/64 | 1–255 |
| `SENSor:AVErage <n>` | patrz opis | — | 1/8/32/64 | 1–255 |
| `SENSor:PRECision?` | — | string / NaN | NaN | ✓ |
| `SENSor:PRECision <m>` | LOW/MEDIUM/HIGH | — | ✗ | ✓ |
| `SENSor:SOFTReset` | — | — | ✓ | ✓ |
| `SENSor:HEATer` | — | — | ✗ | ✓ |
| `SENSor:ALERt:HIGH?` | — | float °C | ✓ | ✗ |
| `SENSor:ALERt:HIGH <t>` | -55 … +150 | — | ✓ | ✗ |
| `SENSor:ALERt:LOW?` | — | float °C | ✓ | ✗ |
| `SENSor:ALERt:LOW <t>` | -55 … +150 | — | ✓ | ✗ |
| `SENSor:ALERt:STATus?` | — | string | ✓ | ✗ |
| `SENSor:MODe?` | — | string | ✓ | ✗ |
| `SENSor:MODe <m>` | CONT/SHUT/ONES | — | ✓ | ✗ |
| `SENSor:CONVrate?` | — | uint 0–7 | ✓ | ✗ |
| `SENSor:CONVrate <r>` | 0–7 | — | ✓ | ✗ |

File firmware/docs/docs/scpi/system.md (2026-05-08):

# SYSTem — Komendy systemowe

Komendy `SYSTem:` służą do zarządzania urządzeniem: obsługi błędów, wersjonowania, identyfikacji MCU, restartu i wejścia w tryb aktualizacji firmware.

---

## `SYSTem:ERRor[:NEXT]?`

Odczytuje i usuwa z kolejki następny błąd SCPI.

**Składnia:** `SYSTem:ERRor?` lub `SYSTem:ERRor:NEXT?`  
**Parametry:** brak  
**Odpowiedź:** `<kod>,"<opis>"`

| Wynik | Znaczenie |
|---|---|
| `0,"No error"` | Kolejka błędów jest pusta |
| `-222,"Data out of range"` | Parametr poza dopuszczalnym zakresem |
| `-241,"Hardware missing"` | Czujnik nie wykryty |

```python
err = inst.query('SYSTem:ERRor:NEXT?')
print(err)   # -241,"Hardware missing"
```

!!! tip
    Odczytuj błędy w pętli, dopóki wartość kodu != 0:
    ```python
    while True:
        err = inst.query('SYSTem:ERRor?')
        code = int(err.split(',')[0])
        if code == 0:
            break
        print(f'Błąd: {err}')
    ```

---

## `SYSTem:ERRor:COUNt?`

Zwraca liczbę błędów aktualnie w kolejce.

**Składnia:** `SYSTem:ERRor:COUNt?`  
**Parametry:** brak  
**Odpowiedź:** liczba całkowita ≥ 0

```python
count = int(inst.query('SYSTem:ERRor:COUNt?'))
print(f'Błędów w kolejce: {count}')
```

---

## `SYSTem:VERSion?`

Zwraca numer wersji standardu SCPI zaimplementowanego w urządzeniu.

**Składnia:** `SYSTem:VERSion?`  
**Parametry:** brak  
**Odpowiedź:** `1999` (odpowiada wersji SCPI 1999.0)

```python
print(inst.query('SYSTem:VERSion?'))   # 1999
```

---

## `SYSTem:ID?`

Zwraca numer seryjny MCU.

**Składnia:** `SYSTem:ID? [SHORT|LONG]`  
**Parametry:** opcjonalny wybór formatu

| Parametr | Format | Długość | Źródło danych |
|---|---|---|---|
| `SHORT` (domyślny) | FNV-1a hash 20 bajtów → hex | **8 znaków** | DEVID + REVID + UID 96-bit |
| `LONG` | 20 bajtów danych MCU → hex | **40 znaków** | DEVID + REVID + UID 96-bit |

!!! info "Skład 20 bajtów"
    `HAL_GetDEVID()` (4B) + `HAL_GetREVID()` (4B) + `UID_Word0` (4B) + `UID_Word1` (4B) + `UID_Word2` (4B)

    SHORT to 8-znakowy hash FNV-1a — unikalny per układ, ale nie odwracalny.  
    LONG to 40-znakowy hex dump tych samych 20 bajtów.

```python
print(inst.query('SYSTem:ID?'))          # np. A1B2C3D4  (8 znaków, domyślny SHORT)
print(inst.query('SYSTem:ID? SHORT'))    # A1B2C3D4
print(inst.query('SYSTem:ID? LONG'))     # pełne 40 znaków hex
```

---

## `SYSTem:BOOTloader:ENter`

Wchodzi w tryb USB DFU (Device Firmware Upgrade) w celu aktualizacji firmware.

**Składnia:** `SYSTem:BOOTloader:ENter`  
**Parametry:** brak  
**Odpowiedź:** brak (urządzenie natychmiast restartuje)

```python
inst.write('SYSTem:BOOTloader:ENter')
```

!!! warning "Działanie"
    Komenda:

    1. Wyłącza wyświetlacz
    2. Wyłącza wszystkie przerwania i SysTick
    3. Deinicjalizuje RCC
    4. Przekazuje sterowanie do ROM bootloadera STM32 pod adresem `0x1FFF0000`
    
    Po tej komendzie urządzenie znika z listy portów SCPI i pojawia się jako urządzenie DFU. Użyj **STM32CubeProgrammer** lub `dfu-util` do wgrania nowego firmware.

---

## `SYSTem:RST`

Wykonuje programowy reset MCU.

**Składnia:** `SYSTem:RST`  
**Parametry:** brak  
**Odpowiedź:** brak

```python
inst.write('SYSTem:RST')
```

!!! note
    Odpowiednik komendy `*RST`. Wywołuje `HAL_NVIC_SystemReset()`.

---

## Kody błędów SCPI {#kody-bledow-scpi}

Tabela błędów generowanych przez SDT Board:

### Błędy urządzenia (Device-specific errors)

| Kod | Opis | Przyczyna |
|-----|---|---|
| `-230` | Data corrupt or stale | Błąd CRC w danych z SHT45 |
| `-240` | Hardware error | Błąd komunikacji I2C z TMP117 |
| `-241` | Hardware missing | Czujnik nie wykryty podczas startu |
| `-365` | Time out error | Timeout DMA lub I2C |

### Błędy wykonania (Execution errors)

| Kod | Opis | Przyczyna |
|-----|---|---|
| `-200` | Execution error | Ogólny błąd wykonania |
| `-220` | Parameter error | Zły format parametru |
| `-221` | Settings conflict | Komenda nieobsługiwana przez aktywny czujnik |
| `-222` | Data out of range | Parametr poza dopuszczalnym zakresem |
| `-223` | Too much data | Zbyt dużo danych |
| `-224` | Illegal parameter value | Niedozwolona wartość parametru |
| `-225` | Out of memory | Brak pamięci |

### Błędy składni (Command errors)

| Kod | Opis |
|-----|---|
| `-100` | Command error |
| `-102` | Syntax error |
| `-103` | Invalid separator |
| `-104` | Data type error |
| `-108` | Parameter not allowed |
| `-109` | Missing parameter |
| `-113` | Undefined header |

### Błędy danych pytania (Query errors)

| Kod | Opis |
|-----|---|
| `-410` | Query INTERRUPTED |
| `-420` | Query UNTERMINATED |
| `-430` | Query DEADLOCKED |

---

## Podsumowanie

| Komenda | Parametr | Odpowiedź | Opis |
|---|---|---|---|
| `SYSTem:ERRor[:NEXT]?` | — | `<kod>,"<opis>"` | Następny błąd z kolejki |
| `SYSTem:ERRor:COUNt?` | — | int ≥ 0 | Liczba błędów w kolejce |
| `SYSTem:VERSion?` | — | `1999` | Wersja standardu SCPI |
| `SYSTem:ID? [SHORT\|LONG]` | `SHORT`/`LONG` | string 8 lub 40 znaków | Numer seryjny MCU |
| `SYSTem:BOOTloader:ENter` | — | — | Wejście w tryb DFU |
| `SYSTem:RST` | — | — | Programowy reset MCU |

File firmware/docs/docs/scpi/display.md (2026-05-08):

# DISPlay — Sterowanie wyświetlaczem

Komendy `DISPlay:` pozwalają sterować 8-znakowym wyświetlaczem LED DLR2416: jasnością, stanem, źródłem danych i własnym tekstem.

---

## `DISPlay:BRIGhtness?` / `DISPlay:BRIGhtness`

Odczytuje lub ustawia jasność wyświetlacza.

**Składnia odczytu:** `DISPlay:BRIGhtness?`  
**Składnia zapisu:** `DISPlay:BRIGhtness <percent>`  
**Parametr:** uint — jasność w procentach  
**Zakres:** 1 … 100 (%)  
**Wartość domyślna:** 4 (%)  
**Odpowiedź (odczyt):** uint (%)

```python
print(inst.query('DISPlay:BRIGhtness?'))   # 4
inst.write('DISPlay:BRIGhtness 50')         # 50% jasności
inst.write('DISPlay:BRIGhtness 100')        # maksymalna jasność
```

!!! info "Implementacja PWM"
    Jasność sterowana przez TIM3 CH2 (PC14, AF11). Formuła: `CCR = (1199 × percent) / 100`.  
    TIM3 ARR = 255, więc CCR > 255 → zawsze HIGH. Efektywna regulacja działa dla brightness ≤ 21%,
    powyżej wyświetlacz jest zawsze w pełni jasny.

---

## `DISPlay:STATe?` / `DISPlay:STATe`

Odczytuje lub ustawia stan wyświetlacza (włączony / wyłączony).

**Składnia odczytu:** `DISPlay:STATe?`  
**Składnia zapisu:** `DISPlay:STATe <state>`  
**Parametr:** `0`, `1`, `OFF`, `ON`  
**Odpowiedź (odczyt):** `0` (wyłączony) lub `1` (włączony)

```python
print(inst.query('DISPlay:STATe?'))   # 1

inst.write('DISPlay:STATe OFF')        # wyłącz
inst.write('DISPlay:STATe ON')         # włącz
inst.write('DISPlay:STATe 0')          # wyłącz (alternatywna forma)
inst.write('DISPlay:STATe 1')          # włącz
```

!!! note
    Wyłączenie wyświetlacza (`STATe 0`) odcina sygnał PWM — wyświetlacz gaśnie. Dane są w pamięci i wrócą po włączeniu.

---

## `DISPlay:SOURce?` / `DISPlay:SOURce`

Odczytuje lub ustawia źródło danych wyświetlacza.

**Składnia odczytu:** `DISPlay:SOURce?`  
**Składnia zapisu:** `DISPlay:SOURce <source>`  
**Odpowiedź (odczyt):** `0` lub `1`

| Wartość | Stała (`DisplaySource_t`) | Opis |
|---|---|---|
| `0` | `eDisplaySource_Meas` | Wyświetla automatycznie sformatowane pomiary |
| `1` | `eDisplaySource_Text` | Wyświetla tekst ustawiony przez `DISPlay:TEXT` |

```python
inst.write('DISPlay:SOURce 0')   # tryb pomiarowy (domyślny)
inst.write('DISPlay:SOURce 1')   # tryb tekstowy

print(inst.query('DISPlay:SOURce?'))   # 1
```

---

## `DISPlay:TEXT?` / `DISPlay:TEXT`

Odczytuje lub ustawia tekst wyświetlany na wyświetlaczu (w trybie tekstowym).

**Składnia odczytu:** `DISPlay:TEXT?`  
**Składnia zapisu:** `DISPlay:TEXT "<text>"`  
**Parametr:** string — maksymalnie **8 znaków**  
**Odpowiedź (odczyt):** string (8 znaków, uzupełniony spacjami)

```python
# Ustaw tekst i przełącz w tryb tekstowy
inst.write('DISPlay:SOURce 1')
inst.write('DISPlay:TEXT "HELLO   "')

# Odczyt aktualnego tekstu
text = inst.query('DISPlay:TEXT?')
print(repr(text))   # "HELLO   "
```

!!! warning "Długość tekstu"
    Bufor tekstowy ma 8 znaków. Jeśli podasz krótszy tekst, pozostałe pozycje zostaną wypełnione spacjami. Tekst dłuższy niż 8 znaków zostanie obcięty.

!!! tip "Znak stopnia"
    Wyświetlacz obsługuje specjalny znak stopnia (°) zakodowany jako bajt `0x1B`. Nie da się go przesłać bezpośrednio przez SCPI jako tekst ASCII — jest używany wewnętrznie przez tryb pomiarowy.

---

## Tryb pomiarowy — format wyświetlania

W trybie `SOURce 0` firmware automatycznie formatuje temperaturę na wyświetlacz za pomocą `ConvertFloatTempToChar()`.

Format: dokładnie **8 znaków**. Ostatni znak to `DEGREE_CHAR` (`0x1B`) — specjalny kod stopnia DLR2416. **Nie ma litery 'C'** — wyświetlacz ma tylko 8 pozycji znakowych.

```
Pozycje: [0]  [1][2][3][4][5]  [6][7]
          sign  cyfry/kropka   spc  °

Przykłady:
 25.47 °  →  ' ','2','5','.','4','7',' ',0x1B
-10.11 °  →  '-','1','0','.','1','1',' ',0x1B
 3.500 °  →  ' ','3','.','5','0','0',' ',0x1B
```

- T ∈ [0..9]: format `S D.DDD` (3 miejsca po przecinku)
- T ∈ [10..99]: format `S DD.DD` (2 miejsca po przecinku)
- Wartości ujemne: `'-'` na pozycji [0]

---

## Wyświetlanie błędów

Gdy firmware wykryje błąd czujnika, automatycznie wyświetla go na ekranie w formacie:

```
ERR:-241
```

Każdy błąd jest wyświetlany przez **1,5 sekundy**, a następnie wraca poprzedni widok. Kolejka błędów wyświetlacza mieści maksymalnie **4 wpisy**.

---

## Przykłady

### Komunikat powitalny

```python
inst.write('DISPlay:BRIGhtness 80')
inst.write('DISPlay:SOURce 1')
inst.write('DISPlay:TEXT "SDT INIT"')
time.sleep(2)
inst.write('DISPlay:SOURce 0')   # wróć do pomiarów
```

### Wyłączenie wyświetlacza w nocy

```python
import datetime

hour = datetime.datetime.now().hour
if 23 <= hour or hour < 7:
    inst.write('DISPlay:STATe OFF')
else:
    inst.write('DISPlay:STATe ON')
    inst.write('DISPlay:BRIGhtness 30')
```

---

## Podsumowanie

| Komenda | Parametr | Odpowiedź | Opis |
|---|---|---|---|
| `DISPlay:BRIGhtness?` | — | uint 1–100 | Odczyt jasności |
| `DISPlay:BRIGhtness <n>` | 1–100 | — | Ustaw jasność (%) |
| `DISPlay:STATe?` | — | `0` lub `1` | Odczyt stanu |
| `DISPlay:STATe <s>` | 0/1/ON/OFF | — | Włącz/wyłącz |
| `DISPlay:SOURce?` | — | `0` lub `1` | Odczyt źródła |
| `DISPlay:SOURce <s>` | 0/1 | — | Pomiar lub tekst |
| `DISPlay:TEXT?` | — | string 8 znaków | Odczyt tekstu |
| `DISPlay:TEXT "<s>"` | string ≤8 znaków | — | Ustaw tekst |

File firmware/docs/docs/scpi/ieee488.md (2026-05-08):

# IEEE 488.2 — Komendy mandatoryjne

Zestaw 13 komend wymaganych przez standard SCPI V1999.0 sekcja 4.1.1. Wszystkie urządzenia SCPI muszą je implementować.

---

## `*CLS` — Clear Status

Czyści rejestry statusu: ESR (Event Status Register) i opróżnia kolejkę błędów.

**Składnia:** `*CLS`  
**Parametry:** brak  
**Odpowiedź:** brak

```python
inst.write('*CLS')
```

---

## `*ESE` / `*ESE?` — Event Status Enable

Ustawia lub odczytuje maskę rejestru Event Status Enable (ESE).

**Składnia zapisu:** `*ESE <value>`  
**Składnia odczytu:** `*ESE?`  
**Parametry:** `<value>` — liczba całkowita 0–255 (maska bitowa)  
**Odpowiedź:** liczba całkowita (aktualna wartość ESE)

```python
inst.write('*ESE 32')        # ustaw bit PON
print(inst.query('*ESE?'))   # odczyt: 32
```

---

## `*ESR?` — Event Status Register

Odczytuje i zeruje rejestr Event Status Register (ESR).

**Składnia:** `*ESR?`  
**Parametry:** brak  
**Odpowiedź:** liczba całkowita 0–255

```python
esr = int(inst.query('*ESR?'))
```

---

## `*IDN?` — Identification Query

Zwraca ciąg identyfikacyjny urządzenia w formacie SCPI.

**Składnia:** `*IDN?`  
**Parametry:** brak  
**Odpowiedź:** `<producent>,<model>,<numer_seryjny>,<wersja_firmware>`

| Pole | Wartość |
|---|---|
| Producent | `bartkepl` |
| Model | `SDT` |
| Numer seryjny | 8-znakowy hex (FNV-1a hash z DEVID+REVID+UID MCU) |
| Wersja firmware | `1.0` |

```python
print(inst.query('*IDN?'))
# bartkepl,SDT,A1B2C3D4,1.0
```

---

## `*OPC` / `*OPC?` — Operation Complete

`*OPC` ustawia bit OPC w ESR po zakończeniu wszystkich operacji.  
`*OPC?` blokuje odpowiedź do momentu zakończenia wszystkich operacji, a następnie zwraca `1`.

**Składnia:** `*OPC` lub `*OPC?`  
**Parametry:** brak  
**Odpowiedź** (`*OPC?`): `1`

```python
inst.write('*OPC')
result = inst.query('*OPC?')   # zwraca "1"
```

---

## `*RST` — Reset

Wykonuje reset urządzenia do stanu domyślnego. Inicjalizuje ponownie wszystkie moduły.

**Składnia:** `*RST`  
**Parametry:** brak  
**Odpowiedź:** brak

```python
inst.write('*RST')
```

!!! note
    Odpowiednik `SYSTem:RST`. Wykonuje reset programowy MCU.

---

## `*SRE` / `*SRE?` — Service Request Enable

Ustawia lub odczytuje maskę rejestru Service Request Enable (SRE).

**Składnia zapisu:** `*SRE <value>`  
**Składnia odczytu:** `*SRE?`  
**Parametry:** `<value>` — liczba całkowita 0–255  
**Odpowiedź:** liczba całkowita

```python
inst.write('*SRE 16')
print(inst.query('*SRE?'))   # 16
```

---

## `*STB?` — Status Byte

Odczytuje Status Byte Register.

**Składnia:** `*STB?`  
**Parametry:** brak  
**Odpowiedź:** liczba całkowita 0–255

```python
stb = int(inst.query('*STB?'))
```

---

## `*TST?` — Self-Test

Wykonuje autotest urządzenia i zwraca wynik.

**Składnia:** `*TST?`  
**Parametry:** brak  
**Odpowiedź:** `0` — brak błędów, `1` — błąd

| Wartość | Znaczenie |
|---|---|
| `0` | Urządzenie sprawne (czujnik wykryty i działający) |
| `1` | Błąd — czujnik nie wykryty lub w stanie błędu |

```python
result = int(inst.query('*TST?'))
if result != 0:
    print('Autotest: BŁĄD — sprawdź czujnik!')
```

!!! info "Implementacja"
    Autotest sprawdza, czy `g_sensor.type != SENSOR_NONE && g_sensor.type != SENSOR_ERROR`. W przypadku błędu dodaje `-241` (Hardware missing) do kolejki błędów SCPI.

---

## `*WAI` — Wait to Continue

Wstrzymuje dalsze wykonywanie komend do zakończenia wszystkich oczekujących operacji.

**Składnia:** `*WAI`  
**Parametry:** brak  
**Odpowiedź:** brak

```python
inst.write('*WAI')
```

---

## Podsumowanie

| Komenda | Parametr | Odpowiedź | Opis |
|---|---|---|---|
| `*CLS` | — | — | Wyczyść rejestry statusu |
| `*ESE <n>` | int 0–255 | — | Ustaw ESE |
| `*ESE?` | — | int | Odczyt ESE |
| `*ESR?` | — | int | Odczyt i zerowanie ESR |
| `*IDN?` | — | string | Identyfikacja |
| `*OPC` | — | — | Operation Complete (bit) |
| `*OPC?` | — | `1` | Czekaj na zakończenie |
| `*RST` | — | — | Reset urządzenia |
| `*SRE <n>` | int 0–255 | — | Ustaw SRE |
| `*SRE?` | — | int | Odczyt SRE |
| `*STB?` | — | int | Status Byte |
| `*TST?` | — | `0` lub `1` | Autotest |
| `*WAI` | — | — | Czekaj na zakończenie |

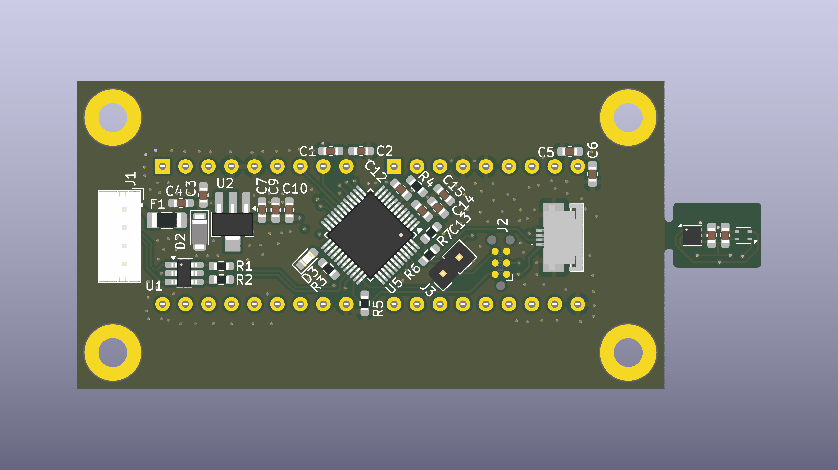
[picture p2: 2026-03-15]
media/SDT_board_front.png

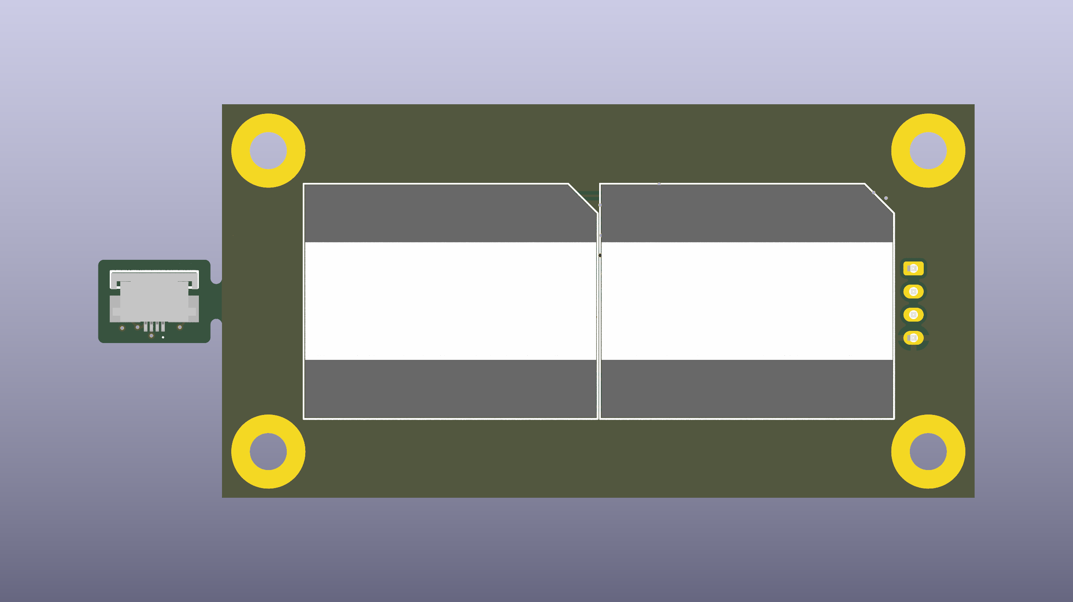
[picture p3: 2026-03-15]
media/SDT_board_back.png

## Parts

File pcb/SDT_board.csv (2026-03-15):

Reference | Qty | Value | DNP | Footprint | Opis
C1,C2,C3,C4,C5,C6,C7,C9,C10,C11,C12,C13,C14,C15,C16 | 15 | 100nF |  | Capacitor_SMD:C_0603_1608Metric_Pad1.08x0.95mm_HandSolder | Unpolarized capacitor
D1,D4 | 2 | HDLO-2416 |  | Display_IntelligentAlpha:DL2416 | .200" High Efficiency Red, 4-Digit 5x7 Dot Matrix Alphanumeric Intelligent Display with Memory/Decoder/Driver
D2 | 1 | SMF5.0CA |  | Diode_SMD:D_SMF | SMF5.0CA
D3 | 1 | LED |  | LED_SMD:LED_0603_1608Metric_Pad1.05x0.95mm_HandSolder | Light emitting diode
F1 | 1 | Polyfuse |  | Fuse:Fuse_1206_3216Metric_Pad1.42x1.75mm_HandSolder | Resettable fuse, polymeric positive temperature coefficient
H1,H2,H3,H4 | 4 | MountingHole_Pad |  | MountingHole:MountingHole_3.2mm_M3_Pad | Mounting Hole with connection
J1 | 1 | USB_B |  | Connector_JST:JST_PH_B4B-PH-K_1x04_P2.00mm_Vertical | USB Type B connector
J2 | 1 | TC2030 |  | Connector:Tag-Connect_TC2030-IDC-NL_2x03_P1.27mm_Vertical | Tag-Connect’s 6-pins connector
J3 | 1 | Conn_01x02 | DNP | Connector_PinHeader_2.54mm:PinHeader_1x02_P2.54mm_Vertical | Generic connector, single row, 01x02, script generated (kicad-library-utils/schlib/autogen/connector/)
J4,J5 | 2 | SFV4R-3STBE1HLF |  | SFV4R3STBE1HLF | 0.50mm Flex Connector, SFV-R Series, 4 Position, Bottom Side Contact, Side Entry Surface Mount ZIF Connector, Halogen Free, Lead Free with Cable-Lock, Gold Flash
R1,R2 | 2 | 22R |  | Resistor_SMD:R_0603_1608Metric_Pad0.98x0.95mm_HandSolder | Resistor
R3 | 1 | 2K |  | Resistor_SMD:R_0603_1608Metric_Pad0.98x0.95mm_HandSolder | Resistor
R4,R5 | 2 | 100K |  | Resistor_SMD:R_0603_1608Metric_Pad0.98x0.95mm_HandSolder | Resistor
R6,R7 | 2 | 10k |  | Resistor_SMD:R_0603_1608Metric_Pad0.98x0.95mm_HandSolder | Resistor
U1 | 1 | USBLC6-2SC6 |  | Package_TO_SOT_SMD:SOT-23-6_Handsoldering | Very low capacitance ESD protection diode, 2 data-line, SOT-23-6
U2 | 1 | LDI1117-3.3U |  | Package_TO_SOT_SMD:SOT-89-3_Handsoldering | 800mA Fixed Low Drop Positive Voltage Regulator, Fixed Output 3.3V, SOT-223
U4 | 1 | TMP117xxDRV |  | Package_SON:WSON-6-1EP_2x2mm_P0.65mm_EP1x1.6mm | Digital Temperature Sensor with I2C/SMBus Interface, 16 bits, ±0.3°C, one-shot conversion, alert, nist traceable, EEPROM, WSON
U5 | 1 | STM32C071CBTx |  | Package_QFP:LQFP-48_7x7mm_P0.5mm | STMicroelectronics Arm Cortex-M0+ MCU, 128KB flash, 24KB RAM, 45 GPIO, LQFP48_GP
U6 | 1 | SHT4x |  | Sensor_Humidity:Sensirion_DFN-4_1.5x1.5mm_P0.8mm_SHT4x_NoCentralPad | Digital Humidity and Temperature Sensor, ±1%RH, ±0.1°C, I2C, 1.08-3.6V, 16bit, DFN-4

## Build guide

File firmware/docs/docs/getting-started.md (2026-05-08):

# Pierwsze kroki

## Wymagania

- Kabel USB-C
- System Windows / Linux / macOS z obsługą USB-TMC
- Opcjonalnie: Python 3.8+ z biblioteką PyVISA lub NI-VISA

---

## Podłączenie urządzenia

1. Podłącz SDT Board do komputera kablem USB-C.
2. Urządzenie zostanie wykryte jako **USB Test and Measurement Class** (USB-TMC).
3. Na wyświetlaczu pojawi się temperatura — oznacza to pomyślne uruchomienie.

!!! note "Sterowniki"
    Na systemie **Windows** może być wymagane zainstalowanie sterownika USBTMC. Polecane opcje:
    
    - **NI-VISA** (National Instruments) — pełna obsługa, instalator dostępny na stronie NI.
    - **PyVISA-py** — sterownik pure-Python, nie wymaga NI-VISA.

---

## Python — PyVISA

### Instalacja

```bash
pip install pyvisa pyvisa-py
```

### Wykrycie urządzenia

```python
import pyvisa

rm = pyvisa.ResourceManager('@py')   # użyj '@py' jeśli nie masz NI-VISA
resources = rm.list_resources()
print(resources)
# Przykład: ('USB0::0xCAFE::0x4000::SDT_A1B2C3D4::INSTR',)
```

!!! info "VID/PID i format numeru seryjnego USB"
    SDT Board używa **VID = `0xCAFE`**, **PID = `0x4000`** (TinyUSB domyślne).  
    Numer seryjny USB ma format **`SDT_<8znakówHash>`**, gdzie hash to FNV-1a z danych MCU (DEVID + REVID + UID 96-bit).  
    Przykład: `SDT_A1B2C3D4`. Wpisz dokładnie tę wartość zamiast `SDT_YOURHASH`.

### Podstawowe komendy

```python
import pyvisa

rm = pyvisa.ResourceManager('@py')
inst = rm.open_resource('USB0::0xCAFE::0x4000::SDT_YOURHASH::INSTR')
inst.timeout = 5000  # ms

# Identyfikacja urządzenia
print(inst.query('*IDN?'))
# Wynik: bartkepl,SDT,ABCDEF12,1.0

# Odczyt temperatury
temp = float(inst.query('SENSor:TEMPerature?'))
print(f'Temperatura: {temp:.4f} °C')

# Odczyt wilgotności (tylko SHT45)
hum = float(inst.query('SENSor:HUMidity?'))
print(f'Wilgotność: {hum:.2f} %RH')

# Typ czujnika
print(inst.query('SENSor:TYPE?'))
# Wynik: "SHT45", "TMP117" lub "DUAL"

inst.close()
```

### Przykład pomiaru ciągłego

```python
import pyvisa
import time

rm = pyvisa.ResourceManager('@py')
inst = rm.open_resource('USB0::0xCAFE::0x4000::SDT_YOURHASH::INSTR')
inst.timeout = 5000

# Ustaw okres odczytu czujnika na 500 ms
inst.write('SENSor:READperiod 500')

try:
    while True:
        temp = float(inst.query('SENSor:TEMPerature?'))
        print(f'{temp:.4f} °C')
        time.sleep(0.5)
except KeyboardInterrupt:
    pass

inst.close()
```

---

## Python — obsługa błędów SCPI

```python
# Sprawdź kolejkę błędów po każdej operacji
def check_errors(inst):
    count = int(inst.query('SYSTem:ERRor:COUNt?'))
    for _ in range(count):
        err = inst.query('SYSTem:ERRor:NEXT?')
        print(f'Błąd SCPI: {err}')

inst.write('SENSor:ALERt:HIGH 200')  # zły zakres
check_errors(inst)
# Błąd SCPI: -222,"Data out of range"
```

---

## Terminal SCPI (ręczny)

Możesz komunikować się z urządzeniem przez dowolny terminal VISA lub przez interaktywny REPL Python z PyVISA.

Przykładowe komendy do wpisania ręcznie:

```
*IDN?
SENSor:TYPE?
SENSor:TEMPerature?
DISPlay:BRIGhtness 50
DISPlay:TEXT "HELLO   "
DISPlay:SOURce 1
```

---

## Wyświetlacz — sterowanie

```python
# Wyłącz wyświetlacz
inst.write('DISPlay:STATe OFF')

# Ustaw jasność 30%
inst.write('DISPlay:BRIGhtness 30')

# Wyświetl własny tekst (max 8 znaków)
inst.write('DISPlay:SOURce 1')       # przełącz na tryb tekstowy
inst.write('DISPlay:TEXT "TEST    "')

# Wróć do wyświetlania pomiarów
inst.write('DISPlay:SOURce 0')
```

---

## Wejście w tryb bootloadera DFU

Aby zaktualizować firmware przez USB DFU:

```python
inst.write('SYSTem:BOOTloader:ENter')
```

!!! warning "Uwaga"
    Po wykonaniu tej komendy urządzenie natychmiast wejdzie w tryb DFU i przestanie odpowiadać przez SCPI. Do wgrania firmware użyj narzędzia **STM32CubeProgrammer** lub `dfu-util`.

---

## Reset urządzenia

```python
# Reset przez SCPI
inst.write('SYSTem:RST')

# Lub standardowy IEEE 488.2
inst.write('*RST')
```

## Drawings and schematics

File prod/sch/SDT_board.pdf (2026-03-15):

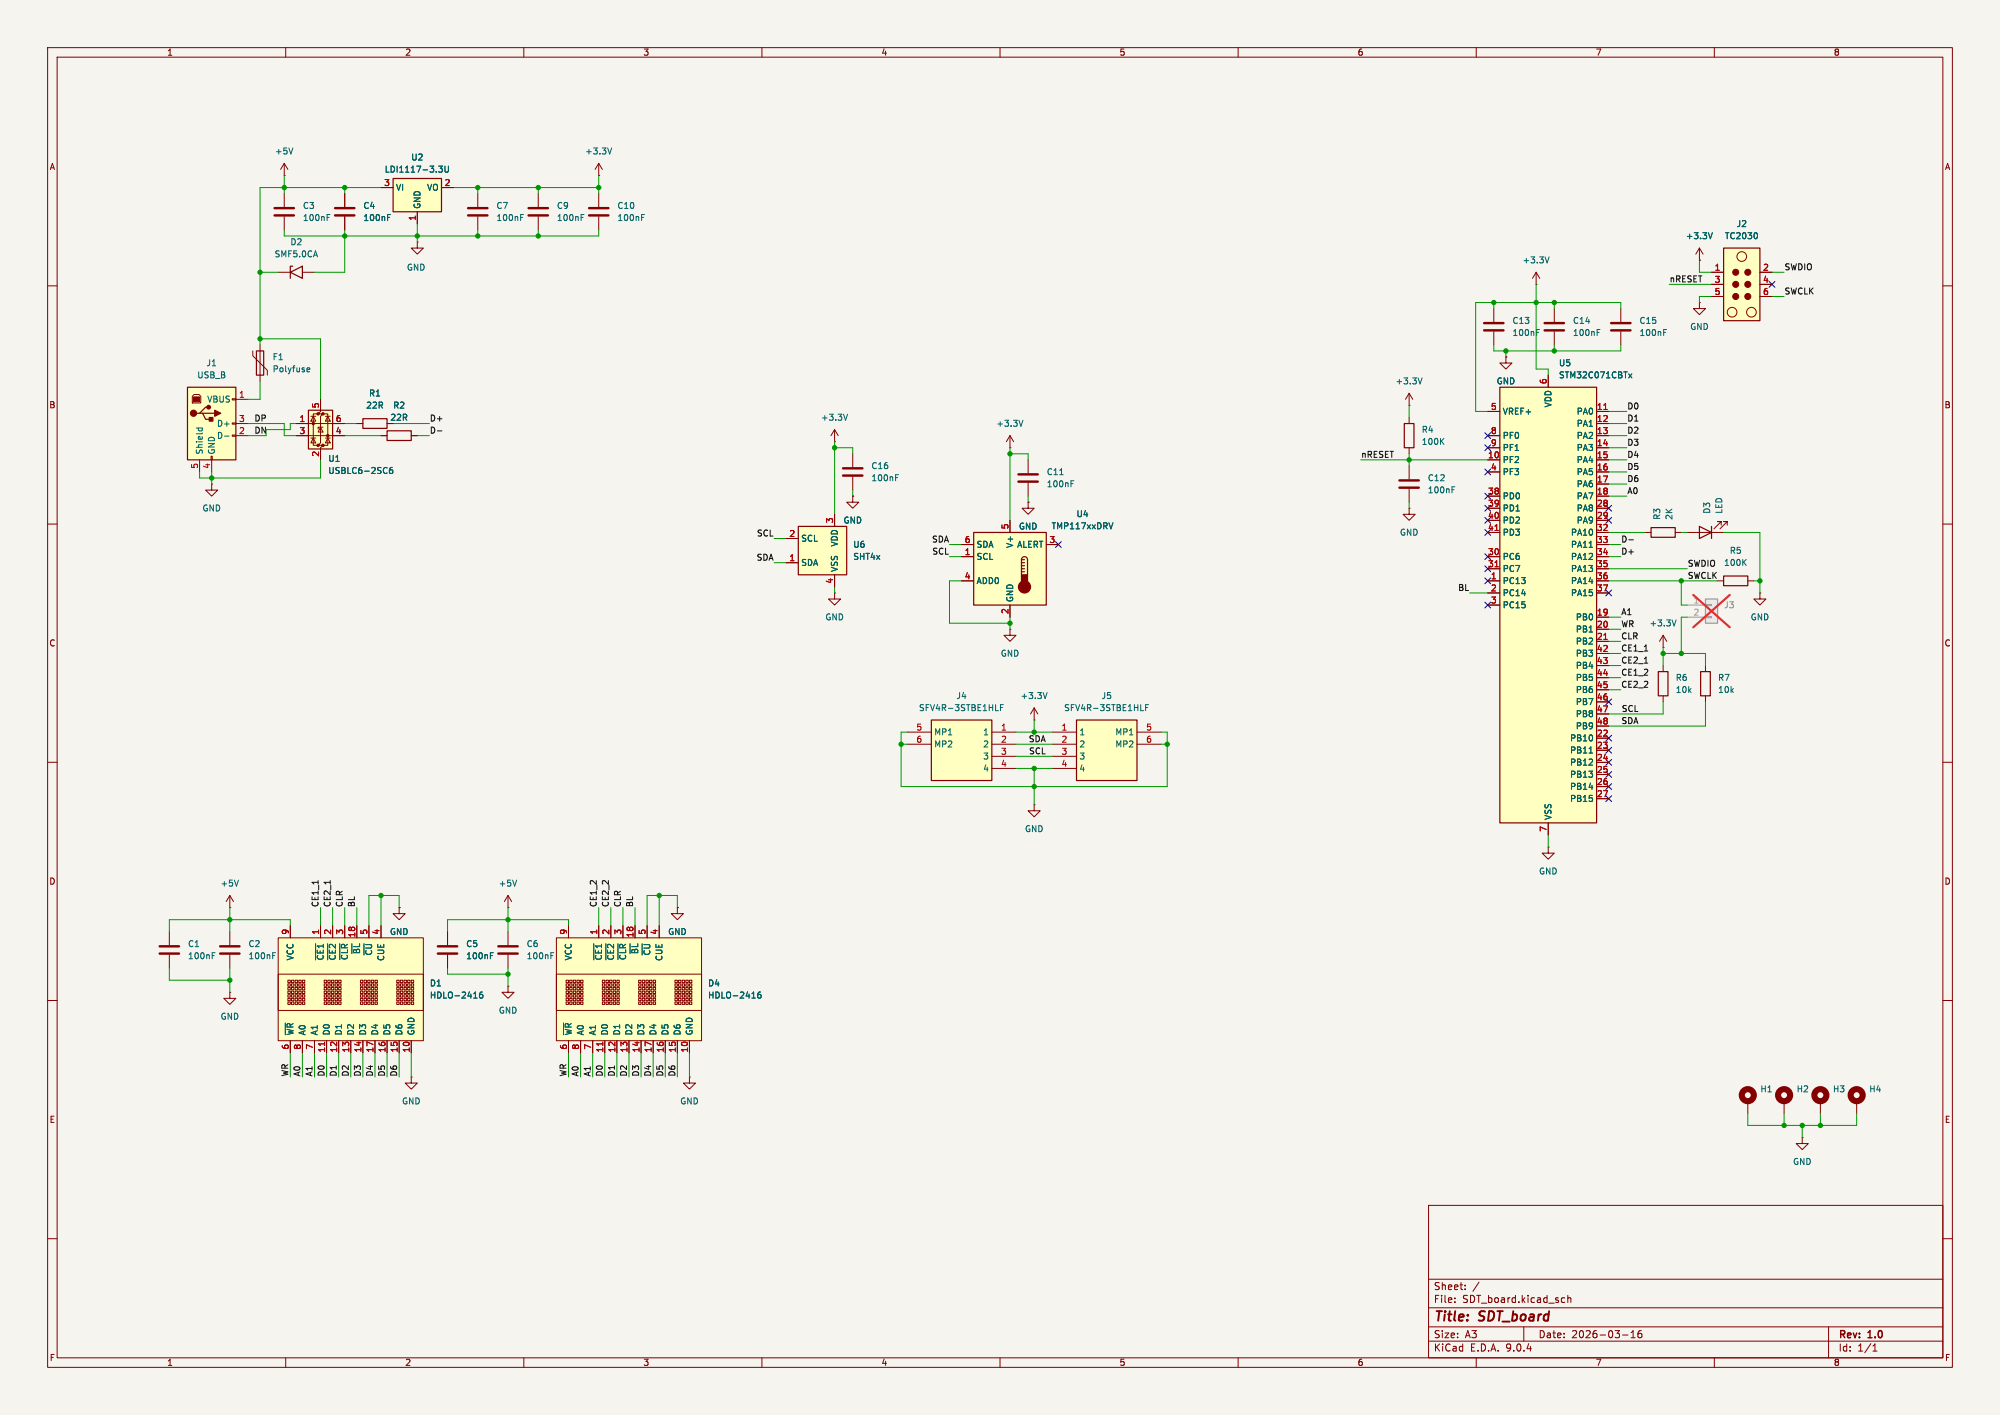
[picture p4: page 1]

4 D5 16 D6 15 GND 10 D1 HDLO-2416 GND GND MP1 5 MP2 6

7 ~{CE1}1 D0 11 ~{CE2}2 D1 12 ~{CLR}3 D2 13 ~{BL}18 D3 14 ~{CU}5 D4 17 CUE

D4 HDLO-2416 VCC

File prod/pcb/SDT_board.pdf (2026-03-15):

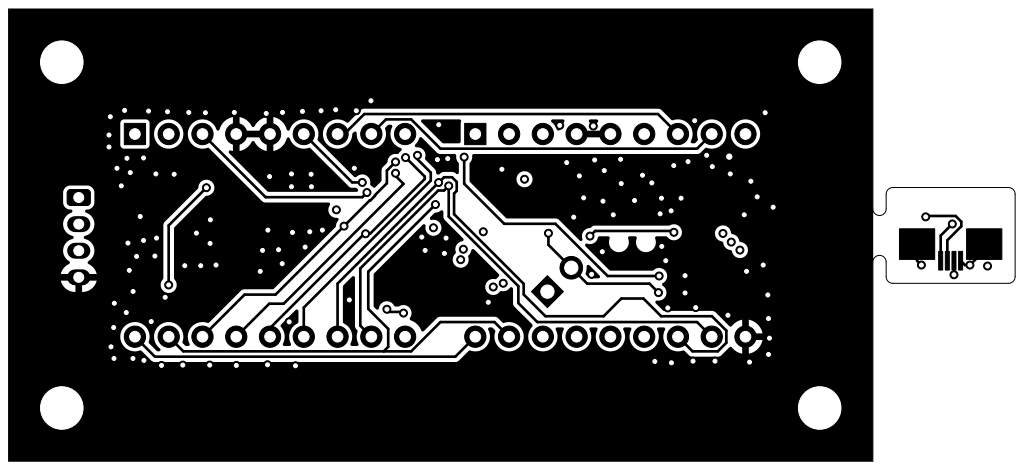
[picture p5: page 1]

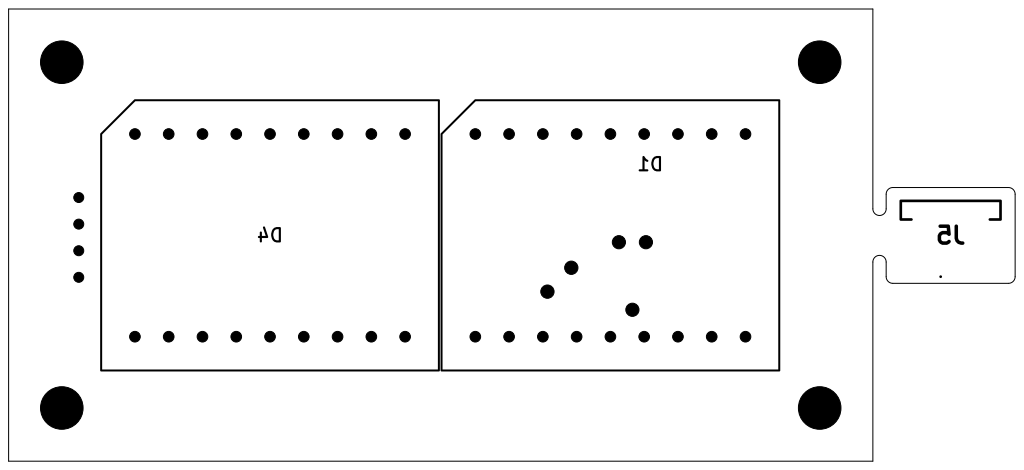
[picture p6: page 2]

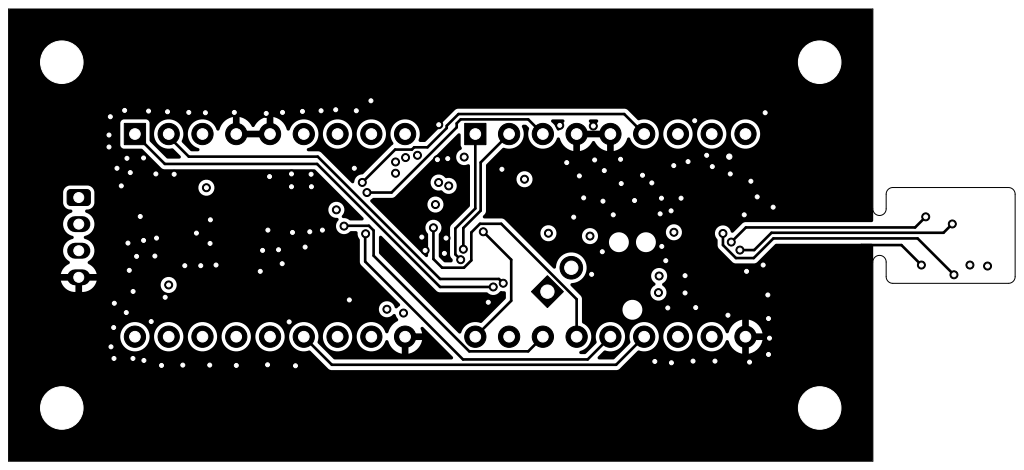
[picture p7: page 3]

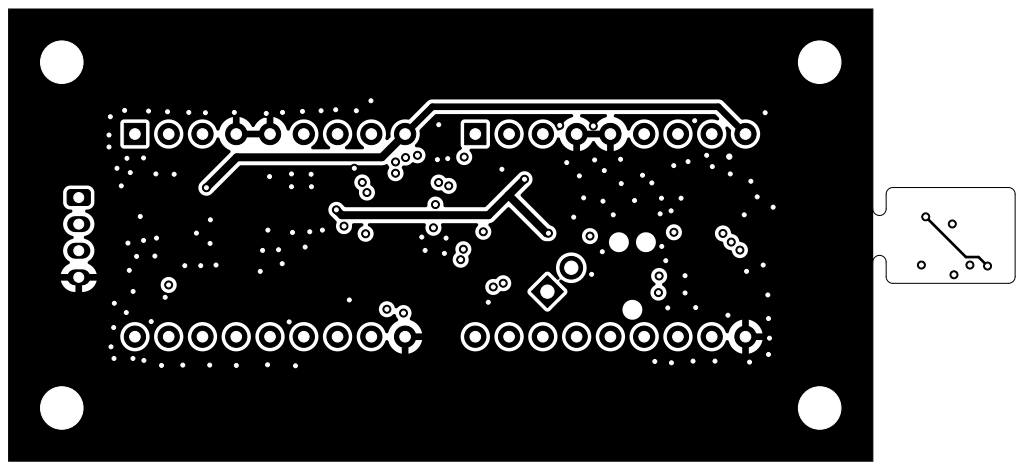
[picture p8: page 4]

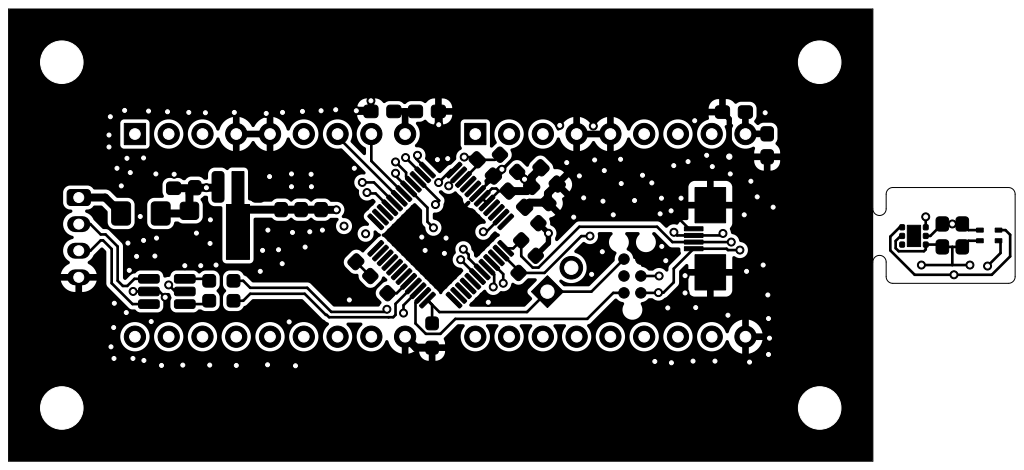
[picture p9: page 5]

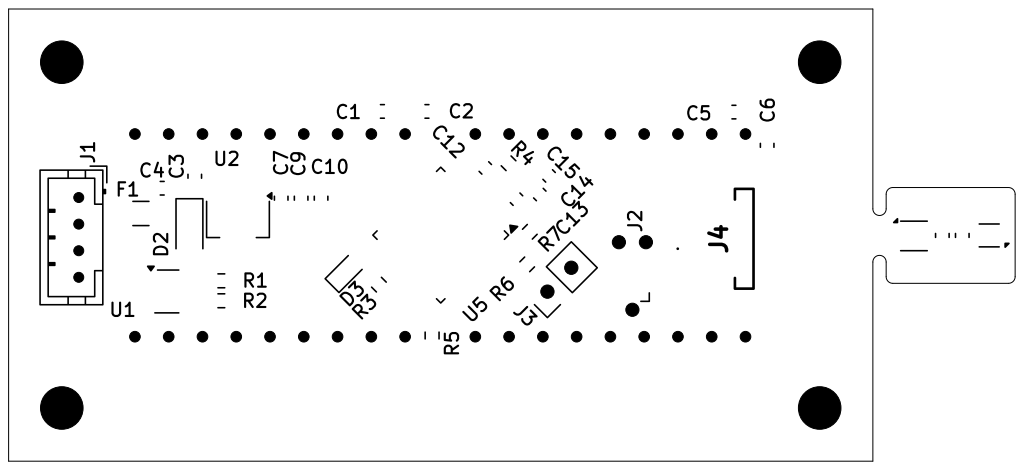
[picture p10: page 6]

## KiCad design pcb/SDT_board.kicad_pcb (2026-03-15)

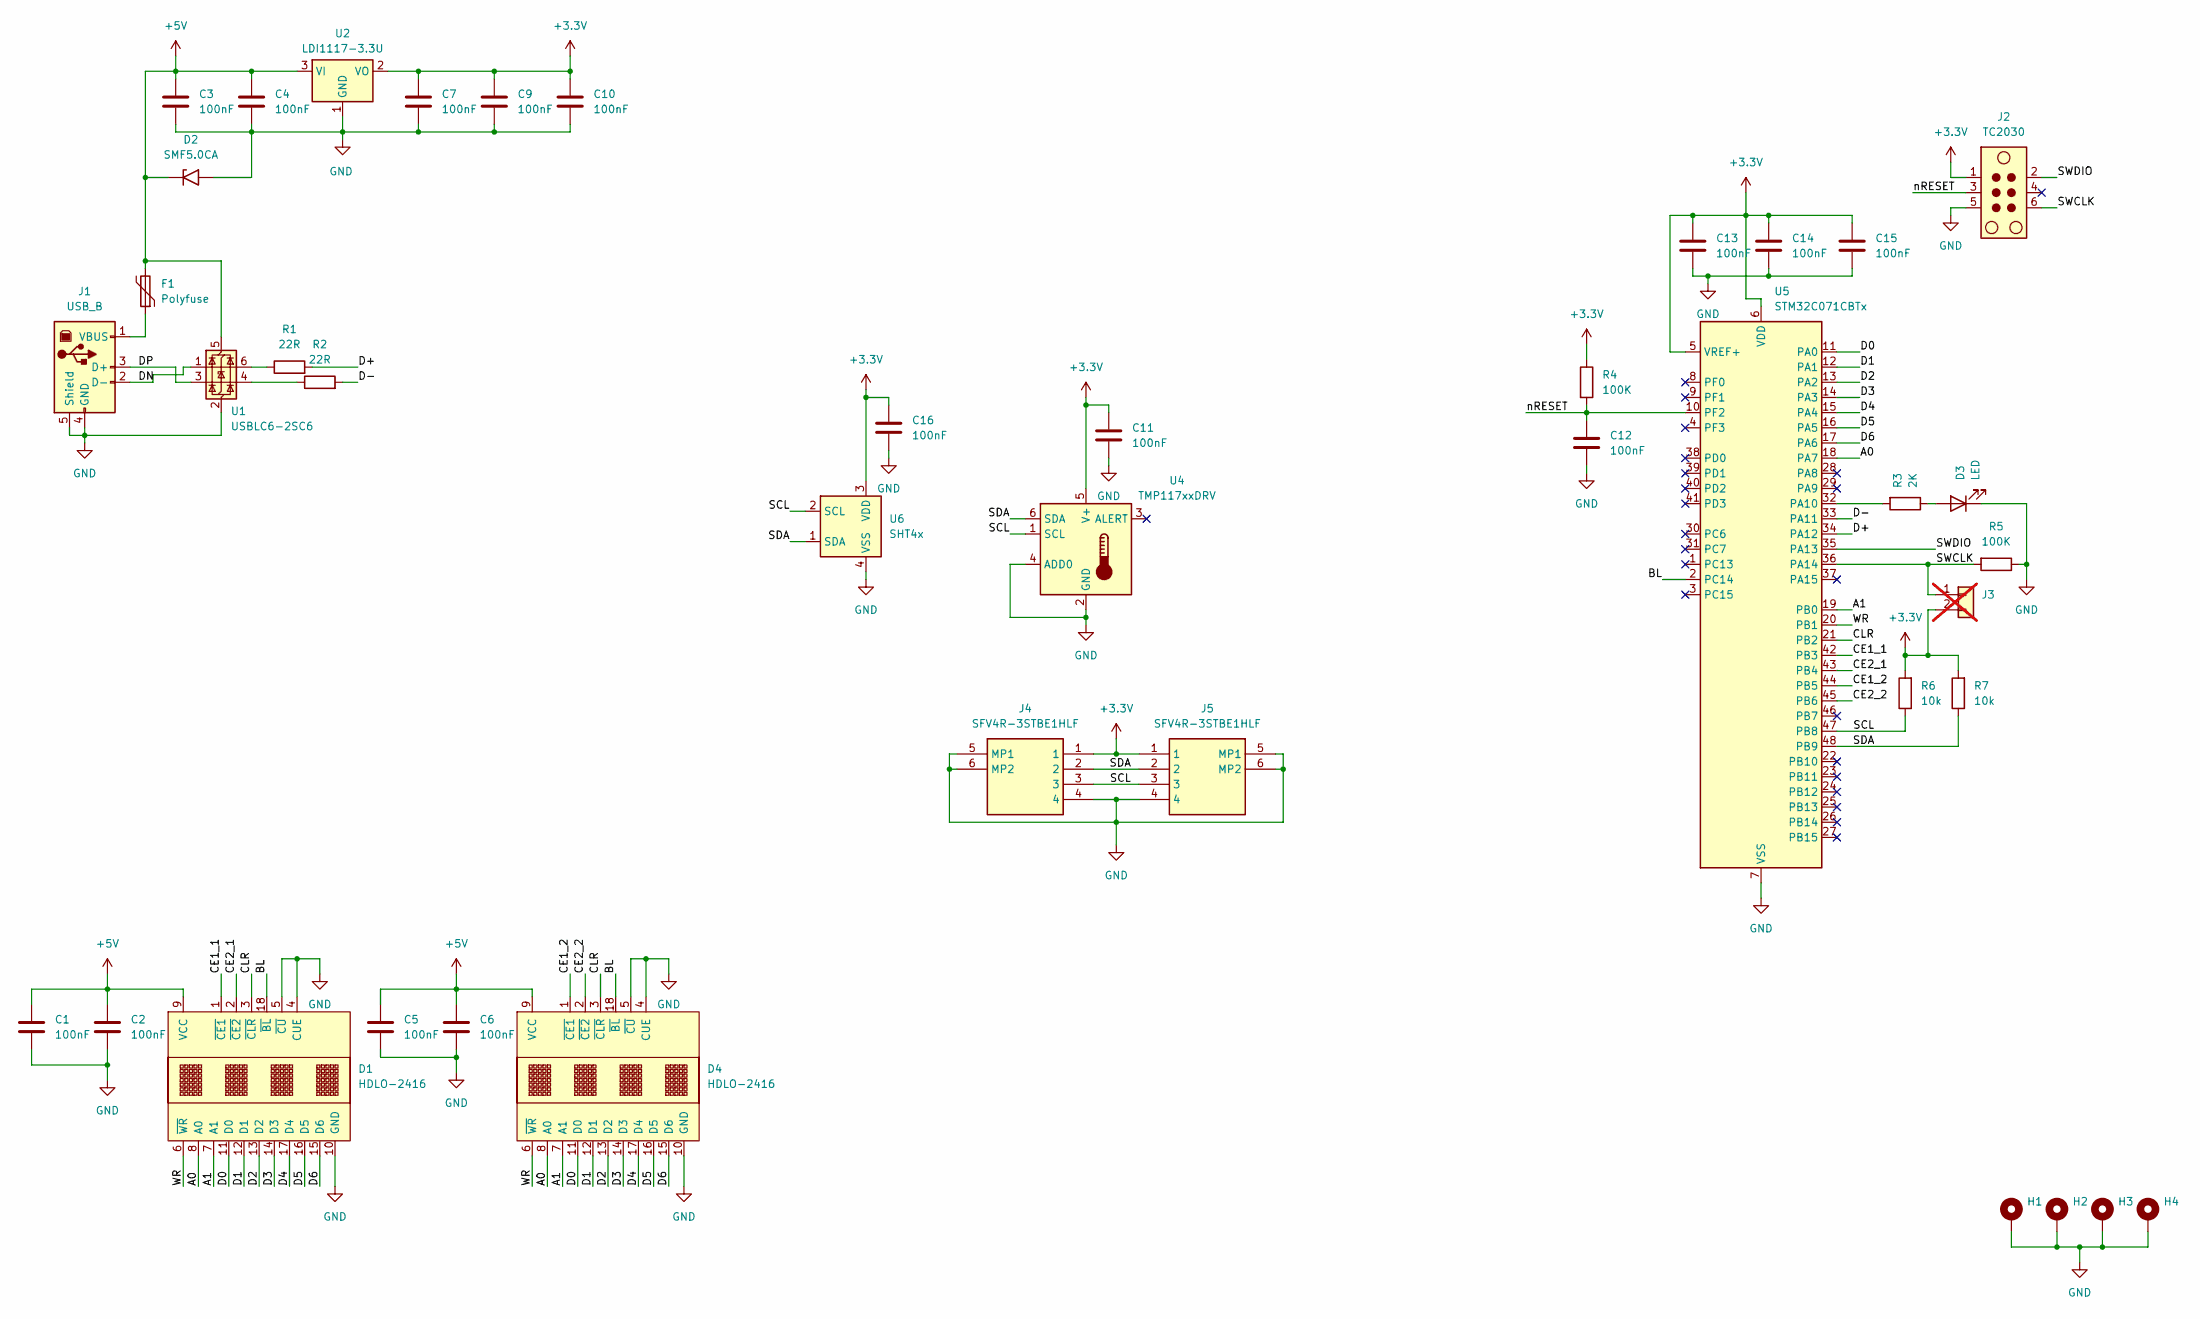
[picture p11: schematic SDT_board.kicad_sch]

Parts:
C1, C2, C3, C4, C5, C6, C7, C9, C10, C11, C12, C13, C14, C15, C16: 100nF; C_0603_1608Metric_Pad1.08x0.95mm_HandSolder
D1, D4: HDLO-2416; DL2416
D2: SMF5.0CA; D_SMF
D3: LED; LED_0603_1608Metric_Pad1.05x0.95mm_HandSolder
F1: Polyfuse; Fuse_1206_3216Metric_Pad1.42x1.75mm_HandSolder
H1, H2, H3, H4: MountingHole_Pad; MountingHole_3.2mm_M3_Pad
J1: USB_B; JST_PH_B4B-PH-K_1x04_P2.00mm_Vertical
J2: TC2030; Tag-Connect_TC2030-IDC-NL_2x03_P1.27mm_Vertical
J3: Conn_01x02; PinHeader_1x02_P2.54mm_Vertical; not fitted
J4, J5: SFV4R-3STBE1HLF; SFV4R3STBE1HLF; Manufacturer_Part_Number SFV4R-3STBE1HLF
R1, R2: 22R; R_0603_1608Metric_Pad0.98x0.95mm_HandSolder
R3: 2K; R_0603_1608Metric_Pad0.98x0.95mm_HandSolder
R4, R5: 100K; R_0603_1608Metric_Pad0.98x0.95mm_HandSolder
R6, R7: 10k; R_0603_1608Metric_Pad0.98x0.95mm_HandSolder
U1: USBLC6-2SC6; SOT-23-6_Handsoldering
U2: LDI1117-3.3U; SOT-89-3_Handsoldering
U4: TMP117xxDRV; WSON-6-1EP_2x2mm_P0.65mm_EP1x1.6mm
U5: STM32C071CBTx; LQFP-48_7x7mm_P0.5mm
U6: SHT4x; Sensirion_DFN-4_1.5x1.5mm_P0.8mm_SHT4x_NoCentralPad

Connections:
+3.3V: C7.1, C9.1, C10.1, C11.1, C13.1, C14.1, C15.1, C16.1, J2.1, J3.2, J4.1, J5.1, R4.1, R6.2, R7.2, U2.2 (VO), U4.5 (V+), U5.5 (VREF+), U5.6 (VDD), U6.3 (VDD)
+5V: C1.1, C2.1, C3.1, C4.1, C5.1, C6.1, D1.9 (VCC), D2.1 (A1), D4.9 (VCC), F1.2, U1.5 (VBUS), U2.3 (VI)
/A0: D1.8 (A0), D4.8 (A0), U5.18 (PA7)
/A1: D1.7 (A1), D4.7 (A1), U5.19 (PB0)
/BL: D1.18 (~BL), D4.18 (~BL), U5.2 (PC14)
/CE1_1: D1.1 (~CE1), U5.42 (PB3)
/CE1_2: D4.1 (~CE1), U5.44 (PB5)
/CE2_1: D1.2 (~CE2), U5.43 (PB4)
/CE2_2: D4.2 (~CE2), U5.45 (PB6)
/CLR: D1.3 (~CLR), D4.3 (~CLR), U5.21 (PB2)
/D0: D1.11 (D0), D4.11 (D0), U5.11 (PA0)
/D1: D1.12 (D1), D4.12 (D1), U5.12 (PA1)
/D2: D1.13 (D2), D4.13 (D2), U5.13 (PA2)
/D3: D1.14 (D3), D4.14 (D3), U5.14 (PA3)
/D4: D1.17 (D4), D4.17 (D4), U5.15 (PA4)
/D5: D1.16 (D5), D4.16 (D5), U5.16 (PA5)
/D6: D1.15 (D6), D4.15 (D6), U5.17 (PA6)
/D+: R1.2, U5.34 (PA12)
/D-: R2.2, U5.33 (PA11)
/DN: J1.2 (D-), U1.1 (I/O1)
/DP: J1.3 (D+), U1.3 (I/O2)
/SCL: J4.3, J5.3, R6.1, U4.1 (SCL), U5.47 (PB8), U6.2 (SCL)
/SDA: J4.2, J5.2, R7.1, U4.6 (SDA), U5.48 (PB9), U6.1 (SDA)
/SWCLK: J2.6, J3.1, R5.2, U5.36 (PA14)
/SWDIO: J2.2, U5.35 (PA13)
/WR: D1.6 (~WR), D4.6 (~WR), U5.20 (PB1)
/nRESET: C12.1, J2.3, R4.2, U5.10 (PF2)
GND: C1.2, C2.2, C3.2, C4.2, C5.2, C6.2, C7.2, C9.2, C10.2, C11.2, C12.2, C13.2, C14.2, C15.2, C16.2, D1.4 (CUE), D1.5 (~CU), D1.10 (GND), D2.2 (A2), D3.1 (K), D4.4 (CUE), D4.5 (~CU), D4.10 (GND), H1.1, H2.1, H3.1, H4.1, J1.4 (GND), J1.5 (Shield), J2.5, J4.4, J4.5 (MP1), J4.6 (MP2), J5.4, J5.5 (MP1), J5.6 (MP2), R5.1, U1.2 (GND), U2.1 (GND), U4.2 (GND), U4.4 (ADD0), U5.7 (VSS), U6.4 (VSS)
unnamed: D3.2 (A), R3.1
unnamed: F1.1, J1.1 (VBUS)
unnamed: R1.1, U1.6 (I/O1)
unnamed: R2.1, U1.4 (I/O2)
unnamed: R3.2, U5.32 (PA10)

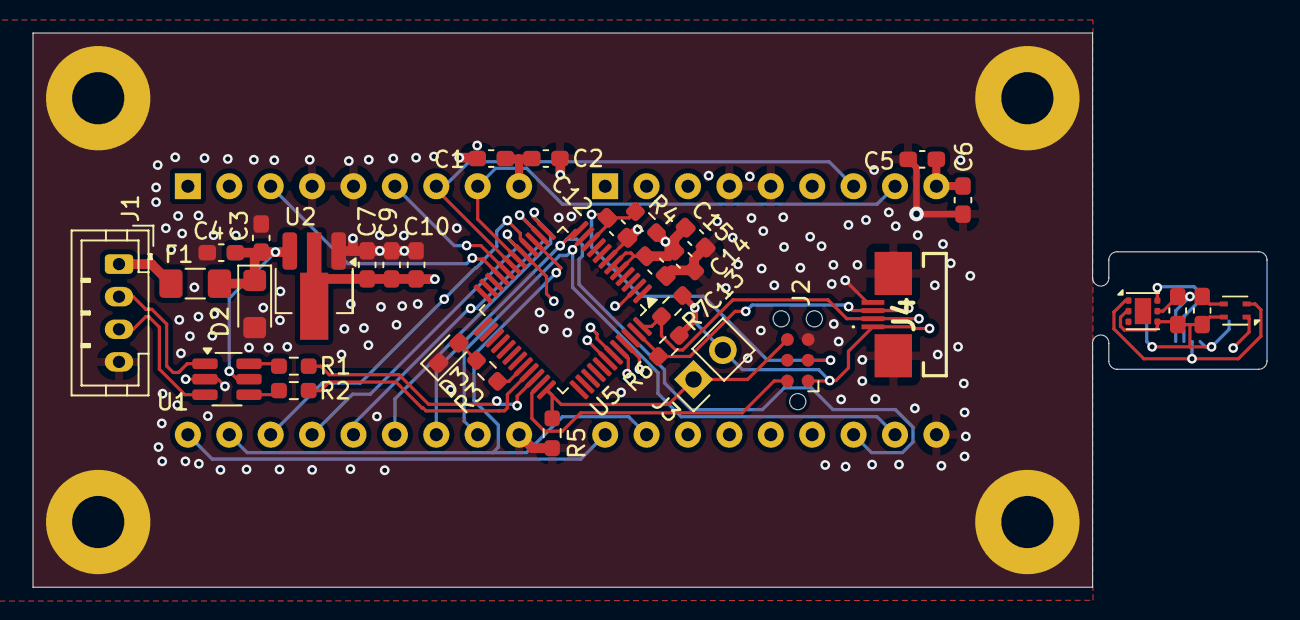
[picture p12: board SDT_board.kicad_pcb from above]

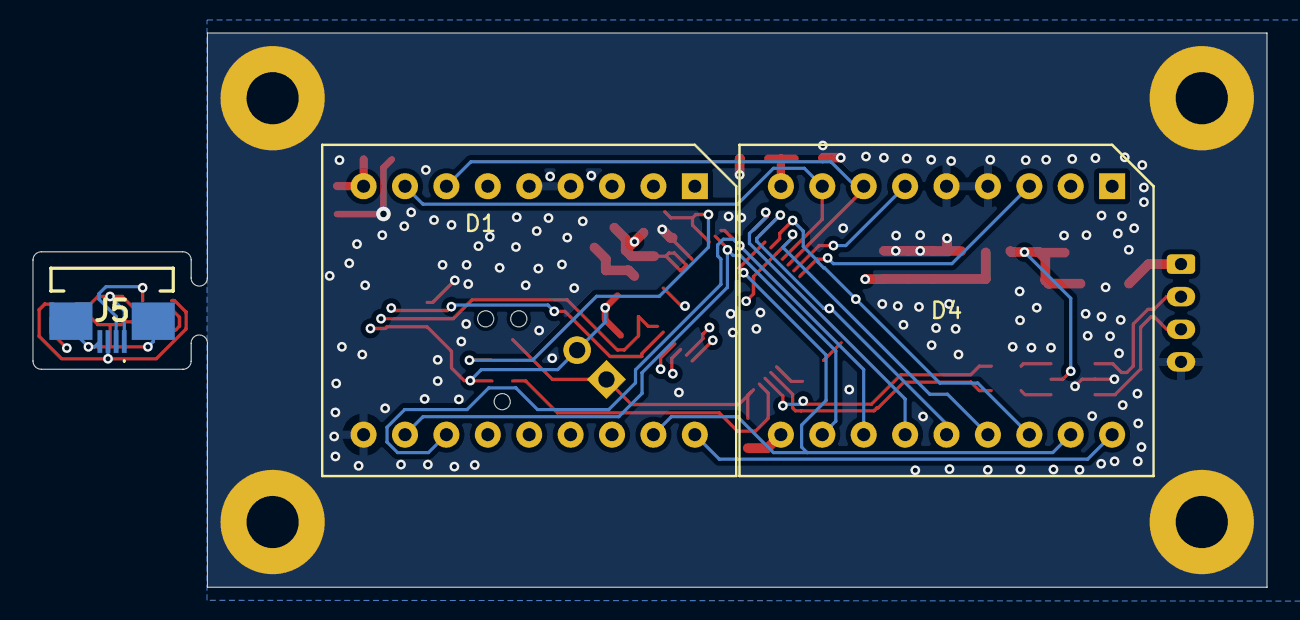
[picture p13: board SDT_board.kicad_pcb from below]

Board: 4 copper layers, 75.7 x 34.0 mm, 41 parts (3 on the bottom side), 33 nets.

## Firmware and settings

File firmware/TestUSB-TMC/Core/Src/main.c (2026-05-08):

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
/* Includes ------------------------------------------------------------------*/
#include "main.h"

/* USER CODE BEGIN Includes */
#include "tusb.h"
#include <ctype.h>
#include <stdio.h>
#include "usbtmc_app.h"
#include <scpi-def.h>
#include <display.h>
#include <sensor.h>
/* USER CODE END Includes */


CRC_HandleTypeDef hcrc;

I2C_HandleTypeDef hi2c1;
DMA_HandleTypeDef hdma_i2c1_rx;
DMA_HandleTypeDef hdma_i2c1_tx;

TIM_HandleTypeDef htim3;

PCD_HandleTypeDef hpcd_USB_DRD_FS;

void SystemClock_Config(void);
static void MX_GPIO_Init(void);
static void MX_DMA_Init(void);
static void MX_I2C1_Init(void);
static void MX_TIM3_Init(void);
static void MX_USB_PCD_Init(void);
static void MX_CRC_Init(void);
/**
  * @brief  The application entry point.
  * @retval int
  */
int main(void)
{

  /* MCU Configuration--------------------------------------------------------*/

  /* Reset of all peripherals, Initializes the Flash interface and the Systick. */
  HAL_Init();

  /* Configure the system clock */
  SystemClock_Config();

  /* Initialize all configured peripherals */
  MX_GPIO_Init();
  MX_DMA_Init();
  MX_I2C1_Init();
  MX_TIM3_Init();
  MX_USB_PCD_Init();
  MX_CRC_Init();
  /* USER CODE BEGIN 2 */
 // AppInit();

  HAL_GPIO_WritePin(LED_GPIO_Port, LED_Pin, GPIO_PIN_SET);
  Sensor_Init(&hi2c1);
  tud_init(BOARD_TUD_RHPORT);
  SCPI_Main_Init();
  Display_Init();
  HAL_GPIO_WritePin(LED_GPIO_Port, LED_Pin, GPIO_PIN_RESET);

  /* USER CODE END 2 */

  /* Infinite loop */
  /* USER CODE BEGIN WHILE */
  while (1)
  {
	  tud_task();
	  usbtmc_app_task_iter();
	  Sensor_Task();
	  SCPI_Main_Poll();
	  Display_task();
    /* USER CODE END WHILE */

    /* USER CODE BEGIN 3 */
  }
  /* USER CODE END 3 */
}

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
/* USER CODE BEGIN 4 */

/**
 * @brief I2C Master Transmission Complete Callback
 * @param hi2c I2C handle
 * @retval None
 */
void HAL_I2C_MasterTxCpltCallback(I2C_HandleTypeDef *hi2c)
{
    // Route to Sensor I2C TX complete handler
    if (hi2c->Instance == I2C1)
    {
        Sensor_I2C_TxComplete_Callback();
    }
}

/**
 * @brief I2C Master Reception Complete Callback
 * @param hi2c I2C handle
 * @retval None
 */
void HAL_I2C_MasterRxCpltCallback(I2C_HandleTypeDef *hi2c)
{
    // Route to Sensor I2C RX complete handler
    if (hi2c->Instance == I2C1)
    {
        Sensor_I2C_RxComplete_Callback();
    }
}

/**
 * @brief I2C Error Callback
 * @param hi2c I2C handle
 * @retval None
 */
void HAL_I2C_ErrorCallback(I2C_HandleTypeDef *hi2c)
{
    // Route to Sensor I2C error handler
    if (hi2c->Instance == I2C1)
    {
        Sensor_I2C_Error_Callback();
    }
}
/* USER CODE END 4 */
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


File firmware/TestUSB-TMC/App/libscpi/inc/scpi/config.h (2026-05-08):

/*-
 * BSD 2-Clause License
 *
 * Copyright (c) 2012-2018, Jan Breuer
 * All rights reserved.
 *
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
 * THIS SOFTWARE IS PROVIDED BY THE COPYRIGHT HOLDERS AND CONTRIBUTORS "AS IS"
 * AND ANY EXPRESS OR IMPLIED WARRANTIES, INCLUDING, BUT NOT LIMITED TO, THE
 * IMPLIED WARRANTIES OF MERCHANTABILITY AND FITNESS FOR A PARTICULAR PURPOSE ARE
 * DISCLAIMED. IN NO EVENT SHALL THE COPYRIGHT HOLDER OR CONTRIBUTORS BE LIABLE
 * FOR ANY DIRECT, INDIRECT, INCIDENTAL, SPECIAL, EXEMPLARY, OR CONSEQUENTIAL
 * DAMAGES (INCLUDING, BUT NOT LIMITED TO, PROCUREMENT OF SUBSTITUTE GOODS OR
 * SERVICES; LOSS OF USE, DATA, OR PROFITS; OR BUSINESS INTERRUPTION) HOWEVER
 * CAUSED AND ON ANY THEORY OF LIABILITY, WHETHER IN CONTRACT, STRICT LIABILITY,
 * OR TORT (INCLUDING NEGLIGENCE OR OTHERWISE) ARISING IN ANY WAY OUT OF THE USE
 * OF THIS SOFTWARE, EVEN IF ADVISED OF THE POSSIBILITY OF SUCH DAMAGE.
 */

/**
 * @file   config.h
 * @date   Wed Mar 20 12:21:26 UTC 2013
 *
 * @brief  SCPI Configuration
 *
 *
 */

#ifndef __SCPI_CONFIG_H_
#define __SCPI_CONFIG_H_

#ifdef	__cplusplus
extern "C" {
#endif

#include "cc.h"

#ifdef SCPI_USER_CONFIG
#include "scpi_user_config.h"
#endif

/* set the termination character(s)   */
#define LINE_ENDING_CR          "\r"    /*   use a <CR> carriage return as termination charcter */
#define LINE_ENDING_LF          "\n"    /*   use a <LF> line feed as termination charcter */
#define LINE_ENDING_CRLF        "\r\n"  /*   use <CR><LF> carriage return + line feed as termination charcters */

#ifndef SCPI_LINE_ENDING
#define SCPI_LINE_ENDING        LINE_ENDING_CRLF
#endif

#ifndef USE_CUSTOM_REGISTERS
#define USE_CUSTOM_REGISTERS 0
#endif

/**
 * Detect, if it has limited resources or it is running on a full blown operating system.
 * All values can be overiden by scpi_user_config.h
 */
#define SYSTEM_BARE_METAL 0
#define SYSTEM_FULL_BLOWN 1

/* This should cover all windows compilers (msvc, mingw, cvi) and all Linux/OSX/BSD and other UNIX compatible systems (gcc, clang) */
#if defined(_WIN32) || defined(_WIN64) || defined(__unix) || defined(__unix__) || defined(__APPLE__)
#define SYSTEM_TYPE SYSTEM_FULL_BLOWN
#else
#define SYSTEM_TYPE SYSTEM_BARE_METAL
#endif

/**
 * Enable full error list
 * 0 = Minimal set of errors
 * 1 = Full set of errors
 *
 * For small systems, full set of errors will occupy large ammount of data
 * It is enabled by default on full blown systems and disabled on limited bare metal systems
 */
/* Enable full SCPI error code set for hardware-specific error reporting */
#ifndef USE_FULL_ERROR_LIST
#define USE_FULL_ERROR_LIST 1
#endif

/**
 * Enable also LIST_OF_USER_ERRORS to be included
 * 0 = Use only library defined errors
 * 1 = Use also LIST_OF_USER_ERRORS
 */
#ifndef USE_USER_ERROR_LIST
#define USE_USER_ERROR_LIST 0
#endif

#ifndef USE_DEVICE_DEPENDENT_ERROR_INFORMATION
#define USE_DEVICE_DEPENDENT_ERROR_INFORMATION SYSTEM_TYPE
#endif

#if USE_DEVICE_DEPENDENT_ERROR_INFORMATION
#ifndef USE_MEMORY_ALLOCATION_FREE
#define USE_MEMORY_ALLOCATION_FREE 1
#endif
#else
#ifndef USE_MEMORY_ALLOCATION_FREE
#define USE_MEMORY_ALLOCATION_FREE 0
#endif
#endif

#ifndef USE_COMMAND_TAGS
#define USE_COMMAND_TAGS 1
#endif

#ifndef USE_DEPRECATED_FUNCTIONS
#define USE_DEPRECATED_FUNCTIONS 1
#endif

#ifndef USE_CUSTOM_DTOSTRE
#define USE_CUSTOM_DTOSTRE 0
#endif

#ifndef USE_UNITS_IMPERIAL
#define USE_UNITS_IMPERIAL 0
#endif

#ifndef USE_UNITS_ANGLE
#define USE_UNITS_ANGLE SYSTEM_TYPE
#endif

#ifndef USE_UNITS_PARTICLES
#define USE_UNITS_PARTICLES SYSTEM_TYPE
#endif

#ifndef USE_UNITS_DISTANCE
#define USE_UNITS_DISTANCE SYSTEM_TYPE
#endif

#ifndef USE_UNITS_MAGNETIC
#define USE_UNITS_MAGNETIC SYSTEM_TYPE
#endif

#ifndef USE_UNITS_LIGHT
#define USE_UNITS_LIGHT SYSTEM_TYPE
#endif

#ifndef USE_UNITS_ENERGY_FORCE_MASS
#define USE_UNITS_ENERGY_FORCE_MASS SYSTEM_TYPE
#endif

#ifndef USE_UNITS_TIME
#define USE_UNITS_TIME SYSTEM_TYPE
#endif

#ifndef USE_UNITS_TEMPERATURE
#define USE_UNITS_TEMPERATURE SYSTEM_TYPE
#endif

#ifndef USE_UNITS_RATIO
#define USE_UNITS_RATIO SYSTEM_TYPE
#endif

#ifndef USE_UNITS_POWER
#define USE_UNITS_POWER 1
#endif

#ifndef USE_UNITS_FREQUENCY
#define USE_UNITS_FREQUENCY 1
#endif

#ifndef USE_UNITS_ELECTRIC
#define USE_UNITS_ELECTRIC 1
#endif

#ifndef USE_UNITS_ELECTRIC_CHARGE_CONDUCTANCE
#define USE_UNITS_ELECTRIC_CHARGE_CONDUCTANCE SYSTEM_TYPE
#endif

/* define local macros depending on existance of strnlen */
#if HAVE_STRNLEN
#define SCPIDEFINE_strnlen(s, l)	strnlen((s), (l))
#else
#define SCPIDEFINE_strnlen(s, l)	BSD_strnlen((s), (l))
#endif

/* define local macros depending on existance of strncasecmp and strnicmp */
#if HAVE_STRNCASECMP
#define SCPIDEFINE_strncasecmp(s1, s2, l) strncasecmp((s1), (s2), (l))
#elif HAVE_STRNICMP
#define SCPIDEFINE_strncasecmp(s1, s2, l) strnicmp((s1), (s2), (l))
#else
#define SCPIDEFINE_strncasecmp(s1, s2, l) OUR_strncasecmp((s1), (s2), (l))
#endif
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

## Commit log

2026-03-19 New USB-TMC firmware, updated Readme
    [scpi.g]
2026-03-23 More updates and fixes
    [display.c, sensor.c, sensor.h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]
2026-03-24 New display task,scpi fixes and modifications
    [Utils.c, display.c, main.c]
2026-03-26 Added Serial No based on DevId Hash, started rewriting Sensor to State machine
2026-05-05 Testing new sensor state machine
2026-05-08 SCPI error handling by claude
    [config.h, display.c, main.c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]

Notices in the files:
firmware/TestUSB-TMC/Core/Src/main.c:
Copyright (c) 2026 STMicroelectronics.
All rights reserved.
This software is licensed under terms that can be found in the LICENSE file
